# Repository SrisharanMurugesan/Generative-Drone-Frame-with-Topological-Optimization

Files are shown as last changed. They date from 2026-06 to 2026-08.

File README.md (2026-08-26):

# Generative Drone Frame with Topological Optimization

This project uses **Fusion 360 Generative Design** to create a lightweight, topology-optimized drone frame while preserving the important mounting points needed for a real FPV drone build.

The goal of this project was to take an existing APEX-style 7-inch drone frame and use generative design to reduce mass while keeping the frame structurally capable enough for electronics, motors, battery weight, and flight loads.

---

## Original Frame

<p align="center">
  Original Drone Frame
</p>

---

## Generatively Optimized Frame

<p align="center">
  Screenshot 2026-08-26 at 12 56 54 AM

</p>

---

# Tutorial: Generative Drone Frame Optimization in Fusion 360

## 1. Create the Base Model

<table>
<tr>

<td width="55%" valign="top">

Obstacle Geometry

</td>

<td width="45%" valign="top">

### Base Model

The first step is to create or import a general model of the object you want to optimize. The key components of this prototype are the regions that you plan to keep, remove, and fuse.

For this project, I used an APEX-style 7-inch drone frame because it is a common frame size that I use for many of my builds.

I wanted to learn how to use Fusion 360's generative design and was curious how Fusion would optimize the frame while keeping the important mounting points and structural regions.

</td>

</tr>
</table>

---

## 2. Create Obstacle Geometry

Obstacle geometry represents the areas that Fusion 360 is **not allowed to optimize into**. These are regions that must stay clear in the final generated design.

<p align="center">
  Obstacle Geometry
</p>

For this drone frame, I created obstacle geometry for:

- Electronics housing
- Antenna location
- Propeller clearance
- Motor clearance regions

I assigned these regions as separate bodies so Fusion 360 would skip them during the optimization process.

---

## 3. Create Preserved Geometry

Preserved geometry defines the regions that **Fusion 360 must retain** during the generative design process. These features ensure that the optimized frame still maintains all critical mounting points and structural faces.

<table>
<tr>
<td width="50%" align="center" valign="top">

Preserved Geometry on Drone Frame

<br>
<b>Preserved Geometry</b>
<br>
<sub>Critical mounting and structural regions are highlighted in green.</sub>

</td>

<td width="50%" align="center" valign="top">

Obstacle and Preserved Geometry Setup

<br>
<b>Design Space Constraints</b>
<br>
<sub>Preserved geometry (green) shown alongside obstacle geometry (red).</sub>

</td>
</tr>
</table>

### Preserved Features

| Region | Purpose |
|---|---|
| **Motor Mounts** | Maintains the mounting pattern and location for each motor |
| **Screw Holes** | Preserves required screw holes |
| **Structural Connections** | Ensures the generated arms remain connected to the frame |
| **Electronics Mounts** | Retains mounting point for electronics |
| **Frame Interfaces** | Maintains critical connections between frame components |

Each preserved feature was created as a **separate body** before being assigned as Preserve Geometry in Fusion 360. Once assigned, these regions appear green and are protected from material removal during generation.

---
## 4. Add Load Cases

<table>
<tr>

<td width="42%" valign="top">

<h3>Load Case Setup</h3>

<p>
Next, I added load cases to represent the major forces acting on the drone frame during flight.
</p>

<p><b>Applied loads included:</b></p>

<ul>
  <li><b>Electronics Weight</b> — downward force from onboard components</li>
  <li><b>Battery Weight</b> — concentrated load from the battery pack</li>
  <li><b>Camera Load</b> — additional payload at the camera mount</li>
  <li><b>Antenna Load</b> — load applied at the antenna mounting location</li>
  <li><b>Motor Thrust</b> — upward forces applied at each motor mount</li>
</ul>

<p>
The most significant load case is <b>motor thrust</b>, since the arms must transfer the upward thrust generated by the motors into the central frame during flight.
</p>

</td>

<td width="58%" align="center" valign="top">

Drone Frame Load Cases

<br>
<b>Applied Flight Loads</b>
<br>
<sub>Force vectors applied to the preserved mounting regions of the drone frame.</sub>

</td>

</tr>
</table>
---

## 5. Set the Generative Objective

For this study, my objective was to **minimize the mass** of the drone frame while still maintaining structural integrity for the expected loads.

I used a safety factor of 3. A safety factor is a multiplier that helps make sure a part can handle more force than it is expected to experience during normal use. For example, a safety factor of 3 means the frame should theoretically handle three times the expected load before failing.

I chose a safety factor of 3 because drone frames experience vibration, crashes, hard landings, and unpredictable flight forces. Since this frame may be 3D printed, I wanted to account for material weakness, layer adhesion, and real-world conditions.

<p align="center">
  Generative Objective and Safety Factor
</p>

---

## 6. Set Manufacturing Constraints

For the manufacturing constraints, I selected an additive manufacturing setup because the frame is intended to be 3D printed.

I set the manufacturing constraint as unrestricted within additive manufacturing. I planned to print this frame on a Bambu Lab A1, which can handle up to 45-degree overhangs. I also used a **3 mm minimum thickness** to help preserve the structure of the design.

<p align="center">
  Additive Manufacturing Constraints
</p>

---

## 7. Select Material

I selected ABS Plastic as the study material because I planned to print the frame with ABS.

ABS is a better choice than PLA for this type of part because it has improved toughness and better heat resistance, which is useful for FPV drone frames and outdoor testing.

<p align="center">
  ABS Material Selection
</p>

---

## 8. Generate the Final Frame

<table>
<tr>
<td width="50%" align="center" valign="top">

Screenshot 2026-08-26 at 1 11 09 AM

</td>

<td width="50%" align="center" valign="top">

Screenshot 2026-08-26 at 1 11 38 AM

</td>
</tr>
</table>

After setting the preserved geometry, obstacle geometry, load cases, generative objective, manufacturing constraints, and material, Fusion 360 generated the optimized drone frame.

The final design removes unnecessary material while maintaining the important mounting locations and structural paths needed for the frame.

---

# Files Included

This repository includes files for viewing, modifying, or recreating the generative design study.

Included files contains:

- Fusion 360 design files
- Generative design study files
- Exported frame models
- STL or 3MF files for printing
- Screenshots from the setup process
- Reference images

---

# Future Improvements

Future improvements for this project include:

- Running additional simulation studies
- Testing different materials such as PETG, Nylon, or Carbon Fiber Nylon
- Adding real flight test results

---

# Author's Note

This project was created to explore Fusion 360’s generative design tools. By defining preserved geometry, obstacle geometry, realistic load cases, material selection, and additive manufacturing constraints, I generated a lightweight drone frame concept that keeps the important mechanical features needed for assembly.

This repository acts as both a project showcase and a basic tutorial for anyone interested in using generative design for drone frames, robotics parts, or lightweight mechanical structures. This was my first experience at using gererative design and it is safe to say that I plan to continue doing so. This project acts as a learning experience for me to expand my CAD boundaries and I found it very fun. I currently have the frame on a drone and it flys really well. I hope you enjoy.

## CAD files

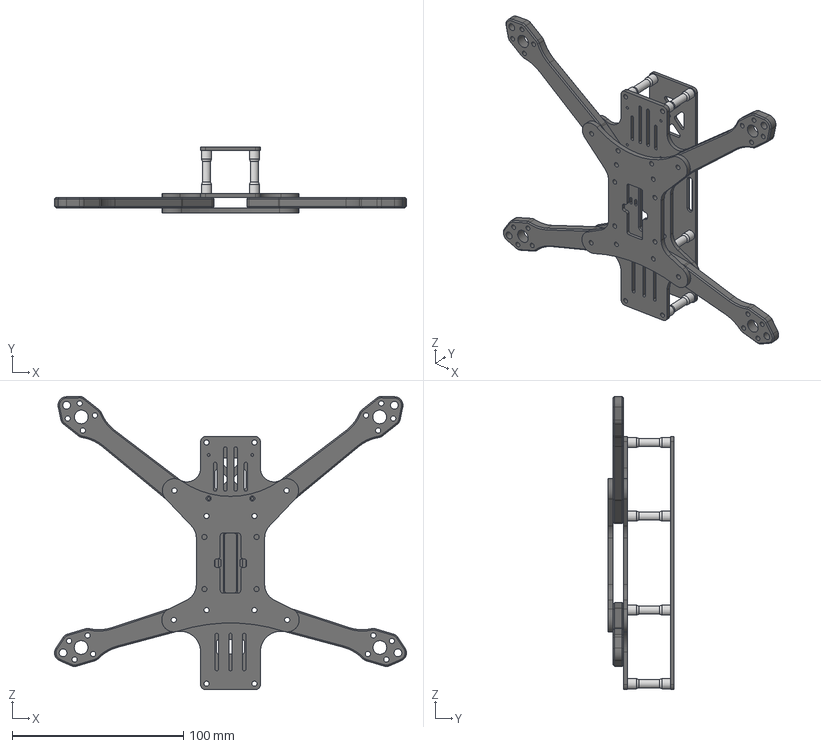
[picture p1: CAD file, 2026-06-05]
01_Original_Frame/Original CFRP Drone Frame.step
205.8 x 38.5 x 171.5 mm
BOTTOM
ARM_SHORT x 2
ARM_LONG x 2
CENTER
SPACER_25MM x 8
TOP

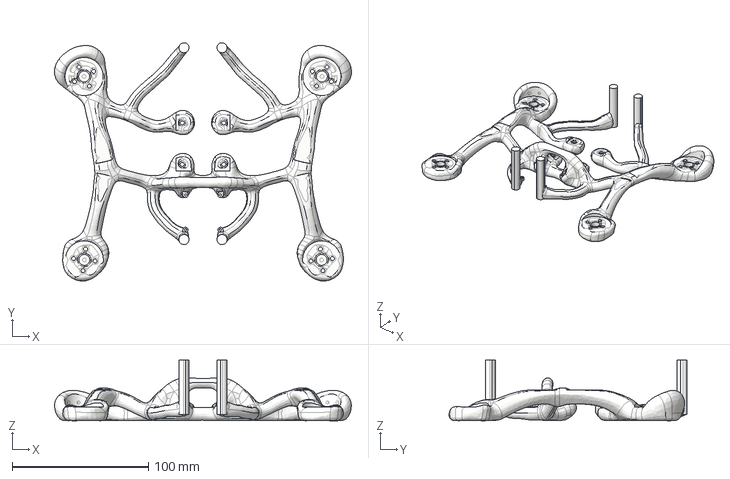
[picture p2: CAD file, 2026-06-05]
04_Final_Generated_Frame/Mesh Final.step
218.3 x 175.0 x 44.5 mm

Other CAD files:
03_Generation_Attempts/Mesh Testing 2.step
03_Generation_Attempts/Mesh Testing 1.step
02_Generative_Setup/Generative Final.f3z
